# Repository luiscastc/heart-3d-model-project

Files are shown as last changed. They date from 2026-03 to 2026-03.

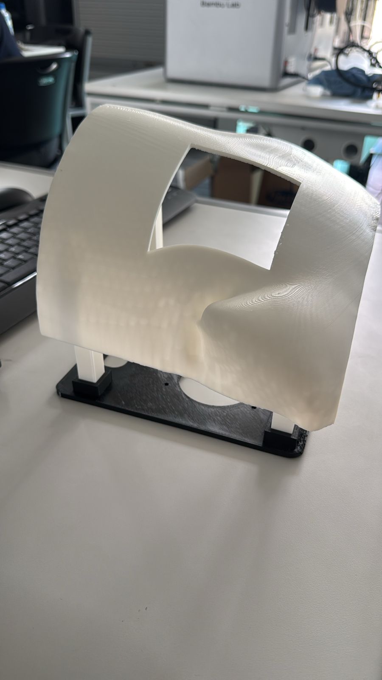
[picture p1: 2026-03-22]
images/printed-thoracic-cover.jpg

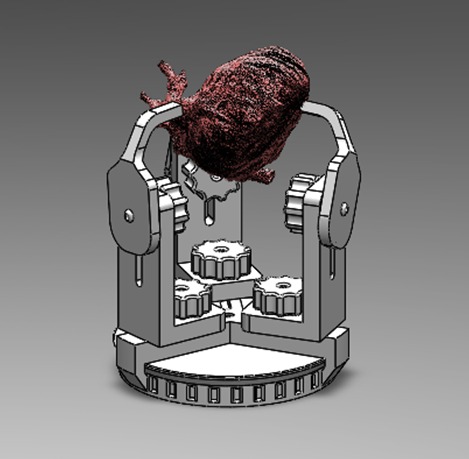
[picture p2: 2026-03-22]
images/heart-fixture-assembly.jpg

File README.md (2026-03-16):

---

# Manufacturing Workflow

The general workflow used in this project includes the following stages:

1. Selection of anatomical cardiac models representing structural heart diseases.
2. Preparation of digital models for additive manufacturing.
3. Selection of suitable flexible polymeric materials.
4. Fabrication of the physical model using additive manufacturing technologies.
5. Post-processing and preparation of the final educational model.

The complete manufacturing guide is provided in the **manual** directory.

---

# Applications

The models developed within this project are intended for:

- Medical education
- Anatomical training
- Simulation of structural heart conditions
- Communication between healthcare professionals and students
- Training environments for medical device development

---

# Model Source

The anatomical heart models used in this project were obtained from the **3D Heart Project**, which provides segmented cardiac models for educational and research purposes.

3D Heart Project  
https://www.3dheartproject.com

The original models remain the property of their respective creators. This repository only documents the manufacturing methodology used to fabricate physical models for educational use.

---

# Intended Use

The models described in this repository are intended exclusively for:

- Educational purposes
- Training and simulation environments

These models are **not intended for patient-specific surgical planning or clinical decision-making**.

---

# Project Context

This work was developed as part of a graduate research project in the field of **medical device engineering**, focused on the development of accessible cardiac models that can support medical education and simulation.

The objective is to explore fabrication methodologies that enable the creation of realistic cardiac models using flexible polymeric materials and additive manufacturing.

---

# License

This repository is released under the **MIT License**.  
See the LICENSE file for additional information.

---

# Acknowledgments

The author acknowledges the contribution of the **3D Heart Project** for providing high-quality segmented cardiac models that enable research and educational initiatives in cardiovascular medicine.

---

# Contact

For questions related to the manufacturing process or the project, please open an issue in this repository.

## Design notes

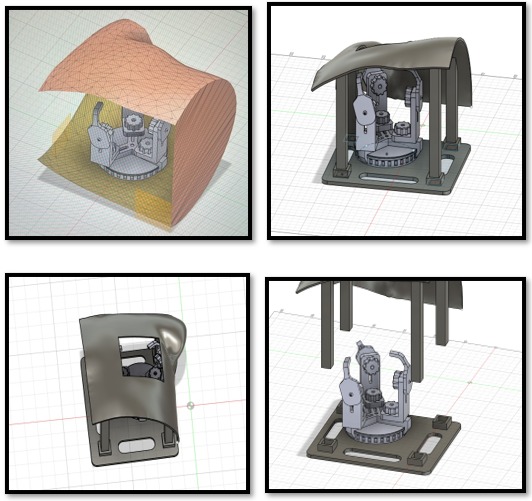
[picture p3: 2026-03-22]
images/support-concept-collage.jpg

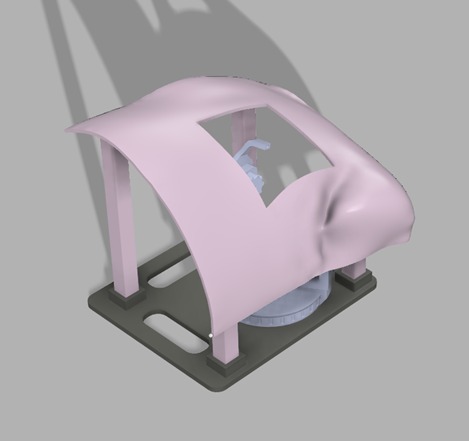
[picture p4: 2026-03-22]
images/cad-thoracic-cover.jpg

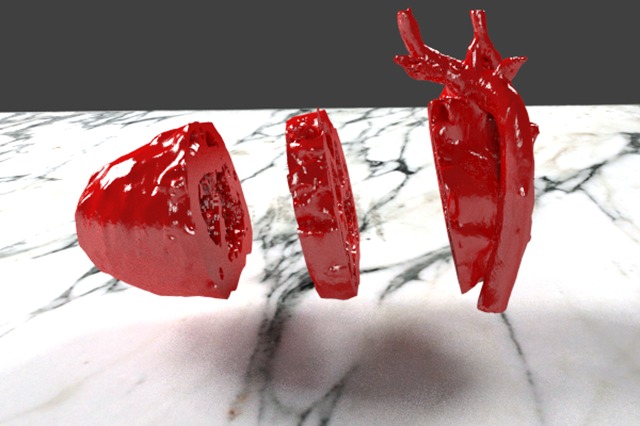
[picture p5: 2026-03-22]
images/heart-model-cross-sections.jpg

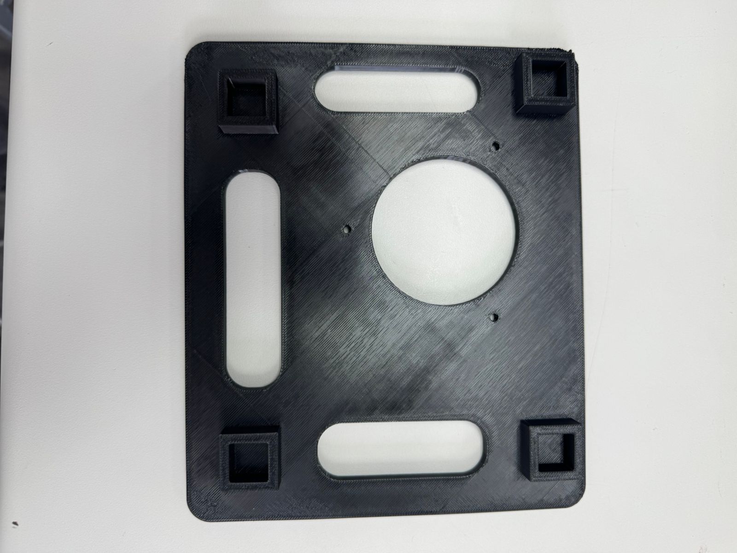
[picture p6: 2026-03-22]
images/base-platform.jpg

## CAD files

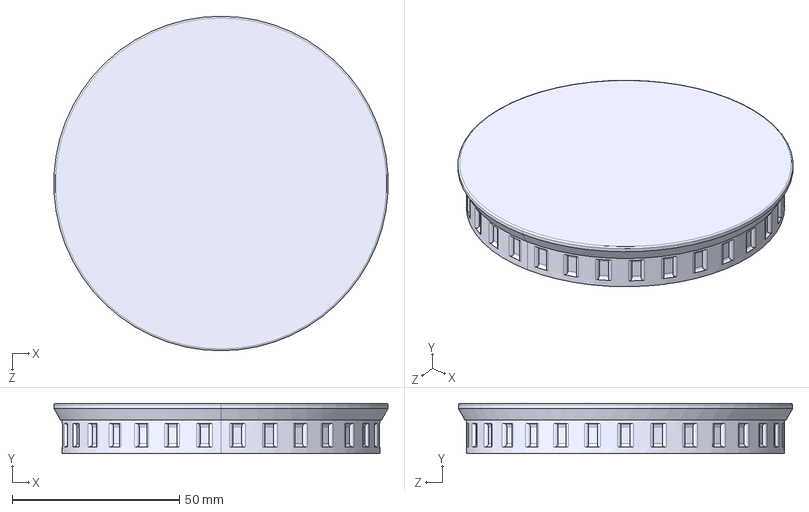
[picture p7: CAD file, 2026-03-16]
Fixture/Heart holder/Plato BaseVer2.STEP
99.9 x 15.0 x 100.0 mm

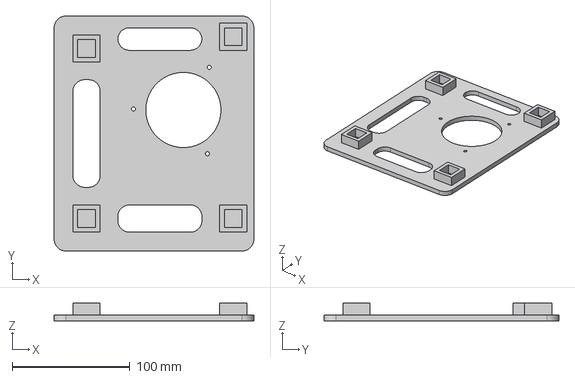
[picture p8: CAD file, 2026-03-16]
Fixture/Test bench/Base.step
170.0 x 200.0 x 15.0 mm

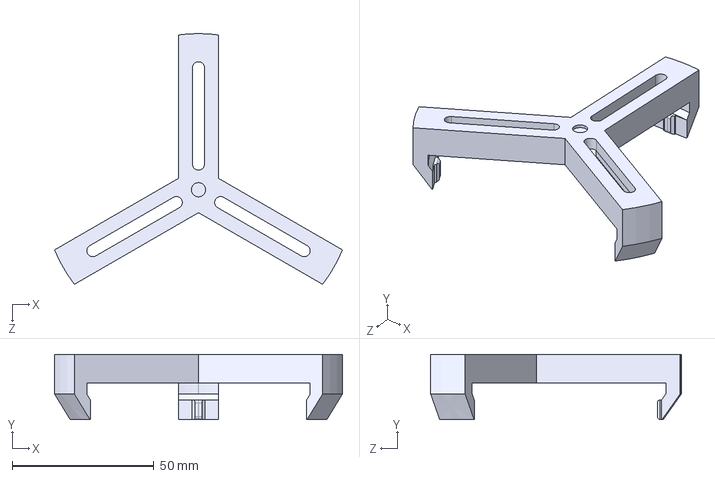
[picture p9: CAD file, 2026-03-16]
Fixture/Heart holder/GuiaAVer2.STEP
101.5 x 23.0 x 88.3 mm

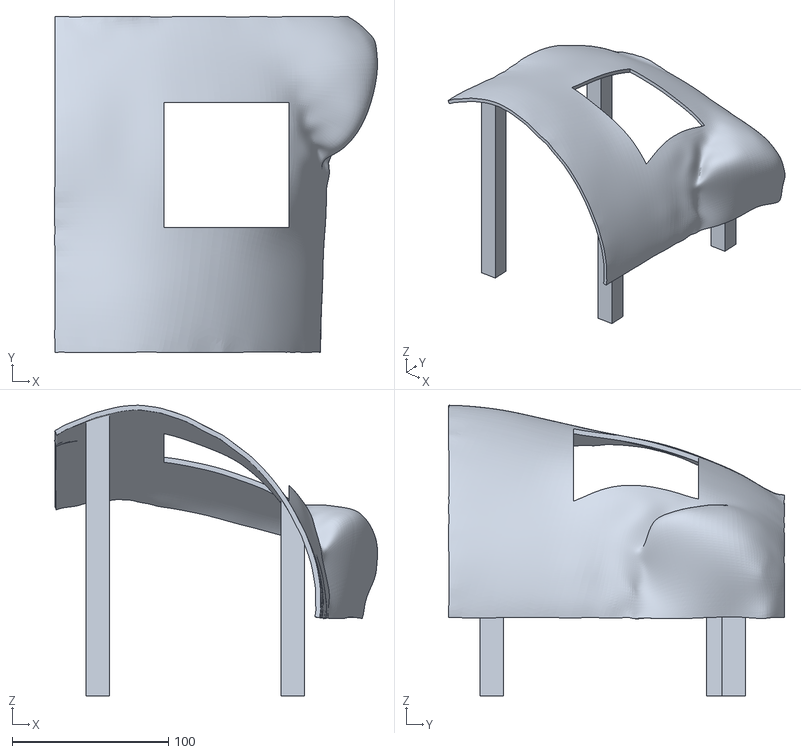
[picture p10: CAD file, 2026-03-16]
Fixture/Test bench/Chest.stl
206.9 x 215.4 x 186.1

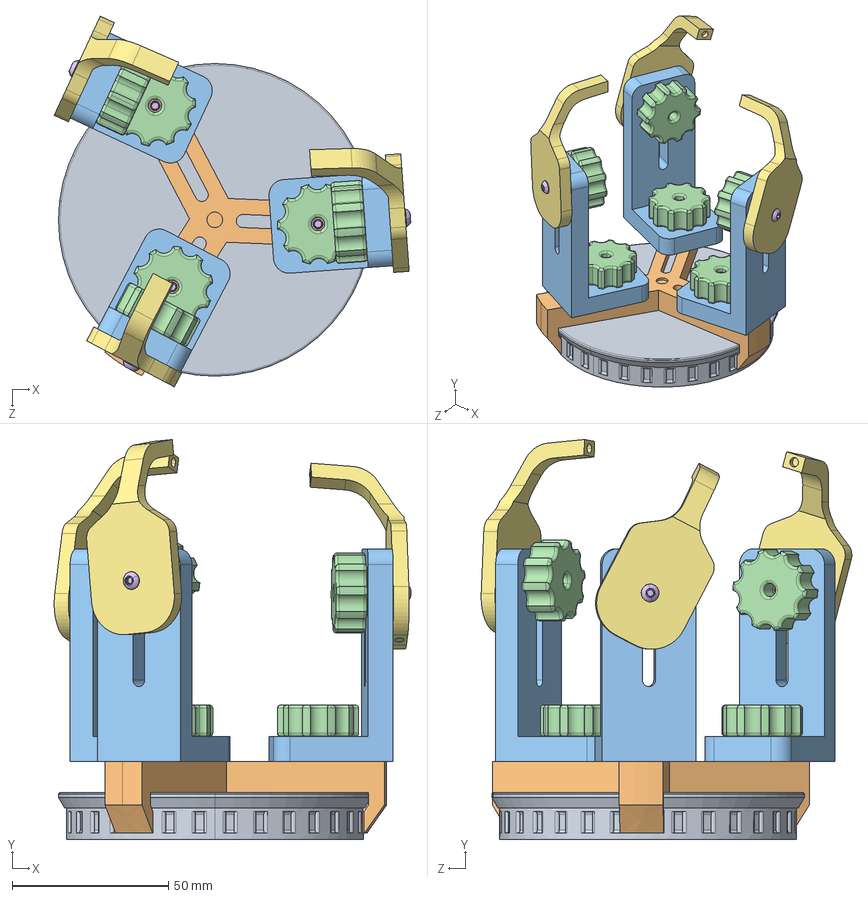
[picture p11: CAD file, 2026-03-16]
Fixture/Heart holder/Fixture Assem Ver2Ver2.STEP
114.1 x 128.0 x 118.6 mm
Plato BaseVer2
GuiaAVer2
Brazo1Ver2 x 3
ThumbwheelVer2 x 6
90592A085_Steel Hex NutVer2_90592A085 x 9
92095A184_Button Head Hex Drive ScrewVer2_92095A184 x 6
Brazo3Ver2_Garra x 3
Iman 3x2Ver2 x 3

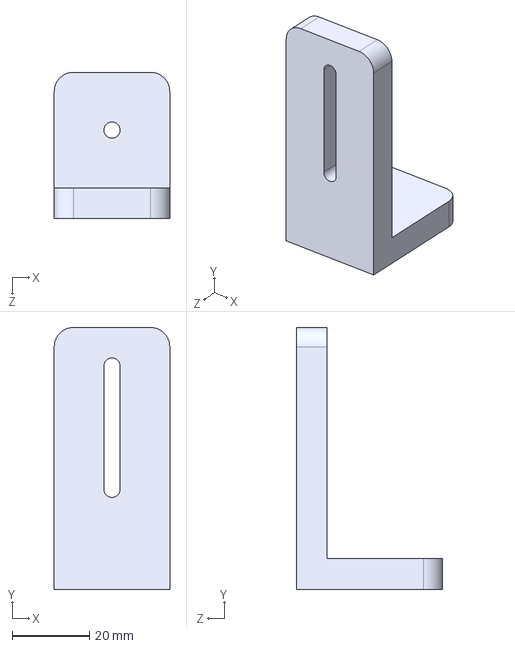
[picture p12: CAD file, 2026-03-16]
Fixture/Heart holder/Brazo1Ver2.STEP
30.0 x 68.0 x 38.0 mm

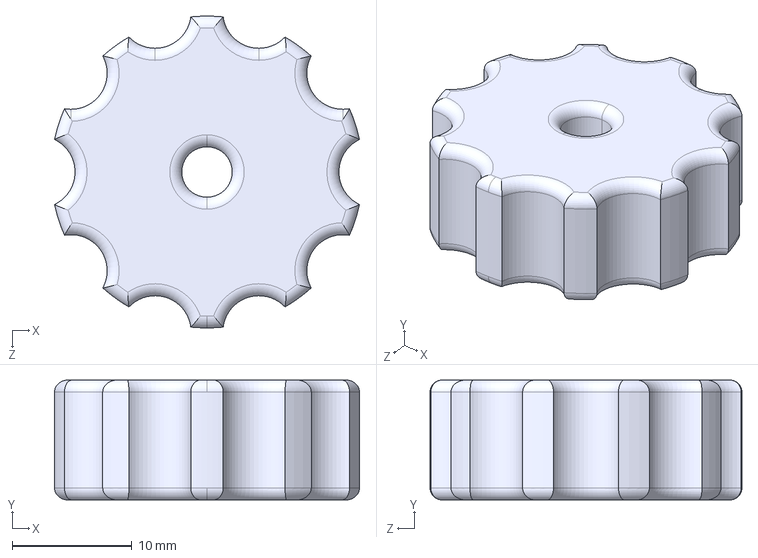
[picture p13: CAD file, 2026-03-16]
Fixture/Heart holder/ThumbwheelVer2.STEP
25.4 x 10.0 x 26.0 mm

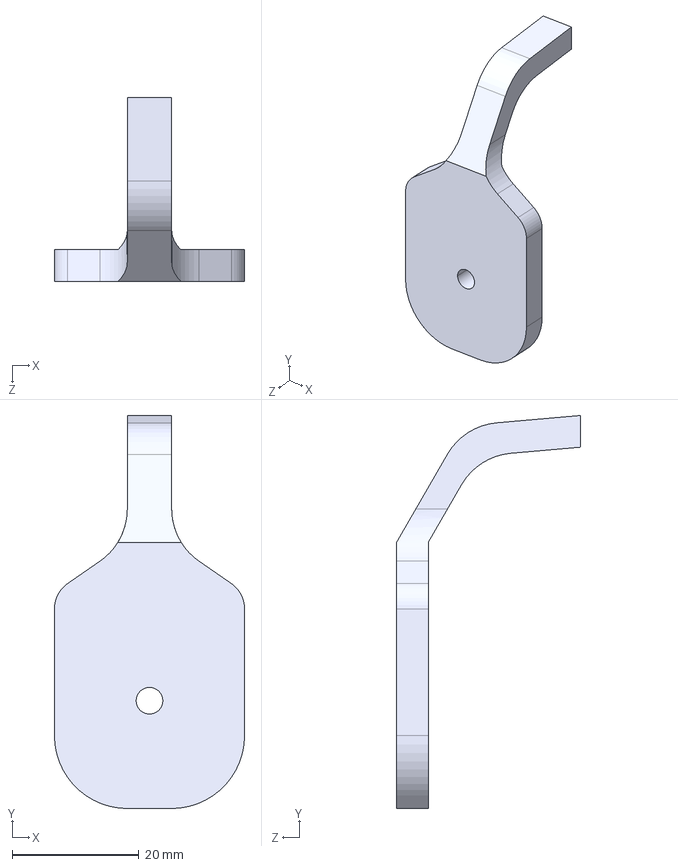
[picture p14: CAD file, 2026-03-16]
Fixture/Heart holder/Brazo3Ver2.STEP
30.0 x 62.0 x 29.0 mm

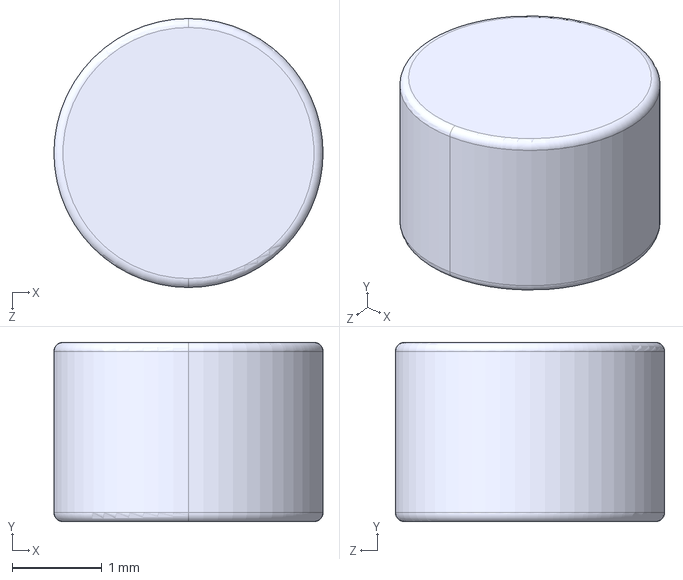
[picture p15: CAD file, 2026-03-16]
Fixture/Heart holder/Iman 3x2Ver2.STEP
3.00 x 2.00 x 3.00 mm

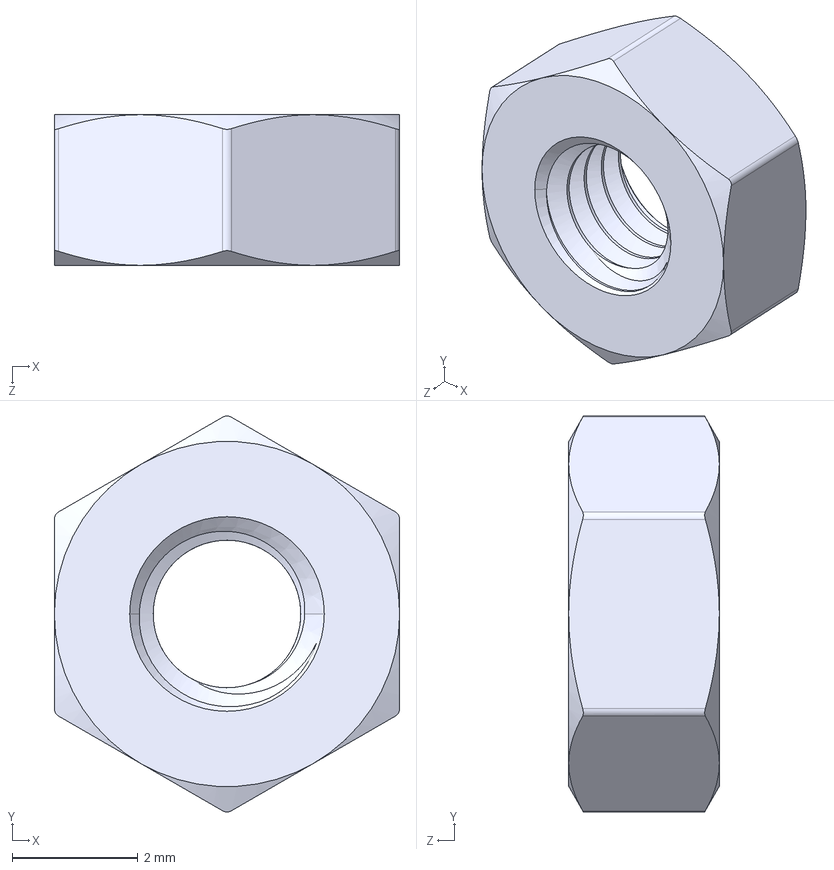
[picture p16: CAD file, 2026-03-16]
Fixture/Heart holder/90592A085_Steel Hex NutVer2.STEP
5.50 x 6.31 x 2.40 mm

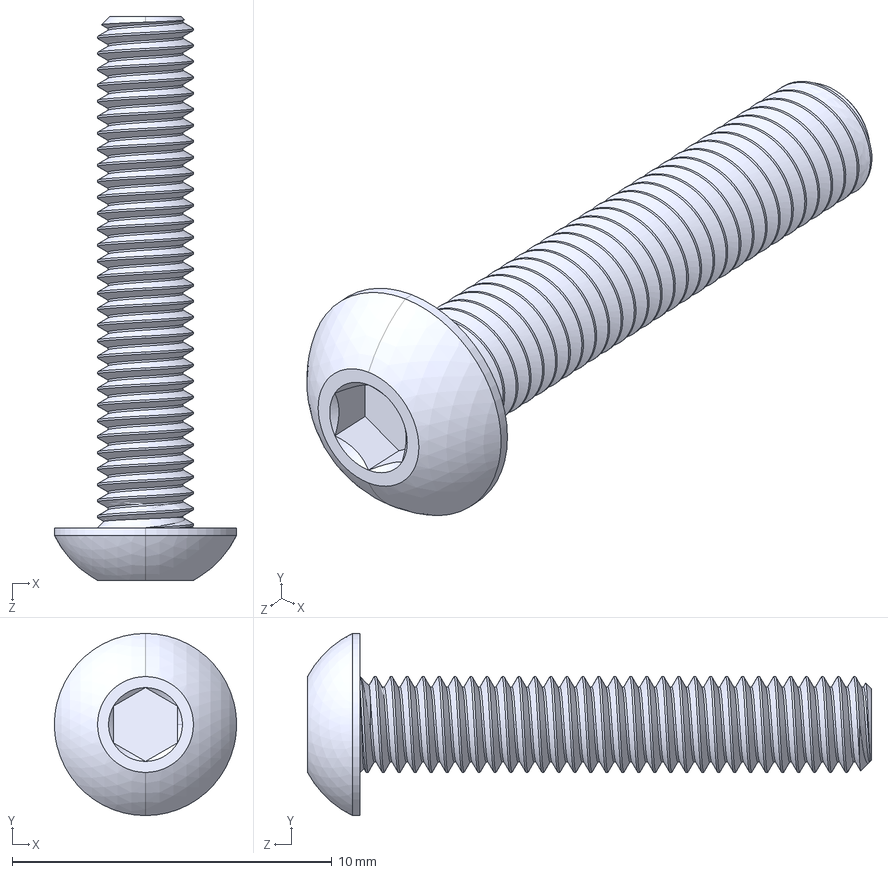
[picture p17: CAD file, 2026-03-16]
Fixture/Heart holder/92095A184_Button Head Hex Drive ScrewVer2.STEP
5.70 x 5.70 x 17.7 mm

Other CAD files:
Fixture/Heart holder/3D_Heart_Model_TOF_WholeVer2.STEP
Fixture/Test bench/base.stl

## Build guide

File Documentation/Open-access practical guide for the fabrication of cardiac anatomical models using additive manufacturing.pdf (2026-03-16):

Open-access practical guide for the fabrication of cardiac anatomical models using additive manufacturing

### 1. Introduction and Purpose of the Guide

This guide describes a reproducible workflow for the acquisition, preparation, manufacturing, post-processing, and validation of three-dimensionally printed anatomical cardiac biomodels intended primarily for educational and anatomical simulation applications.

The development of cardiac biomodels using additive manufacturing has made it possible to tangibly represent complex cardiac structures, facilitating the spatial understanding of structural heart diseases that are often difficult to interpret using only two-dimensional medical images. However, one of the main obstacles to their adoption in academic settings remains the lack of clear and reproducible guidelines documenting the entire manufacturing process.

In response to this need, this appendix proposes a reproducible, open-access guide that documents the workflow for manufacturing cardiac biomodels, including the following stages:

- Obtaining the digital model
- Preparing the model for manufacturing
- Preparing the file for printing
- Fabrication using additive manufacturing
- Post-processing of the biomodel
- Anatomical and functional evaluation

This guide is based on the experience gained during a final graduation project focused on the development of physical models of hearts with structural heart diseases using additive manufacturing and flexible polymeric materials.

Although the research used a pediatric heart with Tetralogy of Fallot as a case study, the procedure described can be applied to any cardiac model available in a digital format suitable for 3D printing.

The guide specifies Formlabs Silicone 40A elastomer as the manufacturing material, selected during the project’s experimental phase for its mechanical properties suitable for simulating soft tissues. It is important to note that, at the time of this guide’s preparation, this material is commercially available only in black, which may limit the visual differentiation of certain anatomical structures. This characteristic is common in elastomeric materials recently introduced to the market and could be modified in future versions of the material through pigmented variants. Alternatives such as the use of coatings or surface pigmentation of the model are not within the scope of this work.

### 2. Scope of the Guide

This guide is intended for the fabrication of flexible cardiac biomodels for non-clinical purposes using additive manufacturing, digital anatomical models, and Formlabs’ Silicone 40A elastomeric material.

Its intended applications include:

- Anatomical education
- Demonstration of congenital heart conditions
- Basic hands-on training in handling cardiac structures
- Simulation of manipulation and suturing on simulated tissues
- Visual support in academic, teaching, or technical communication contexts

The guide can be applied to anatomical models representing structural heart diseases, provided that the digital file has sufficient geometric quality for three-dimensional preparation and printing.

The following are not within the scope of this document:

- The use of the biomodel for personalized surgical planning for specific patients
- Direct clinical decision-making based on the physical model

### 3. Rationale and justification for the proposed workflow

The proposed workflow is based on the results obtained during the project’s experimental phase, in which various additive manufacturing technologies and flexible materials were evaluated for the fabrication of anatomical cardiac models.

Technologies accessible in academic settings were analyzed, such as FDM with flexible materials (e.g., TPU) and elastomeric photopolymerizable resin systems. Although these alternatives offer advantages in terms of cost and availability, they presented limitations in surface fidelity, precision in complex geometries, and behavior during handling.

PolyJet technology, recognized for its high resolution and surface quality, was also evaluated. However, its use proved less practical due to the limited availability of equipment, high operating costs, and reliance on specialized suppliers. Furthermore, in the proof-of-concept tests conducted during the project, the materials evaluated using this technology showed limited performance in cutting and suturing tests, which affects their usefulness in handling and training activities.

Based on this comparative evaluation, Formlabs’ Silicone 40A material was selected, as it demonstrated an appropriate balance between geometric fidelity, elastomeric behavior, and resistance to repeated manipulation. Based on these results, the guide proposes a simplified workflow that allows for the reproduction of the biomodel’s fabrication without the need to repeat the entire material and technology comparison phase.

Consequently, the workflow is structured into the following main stages:

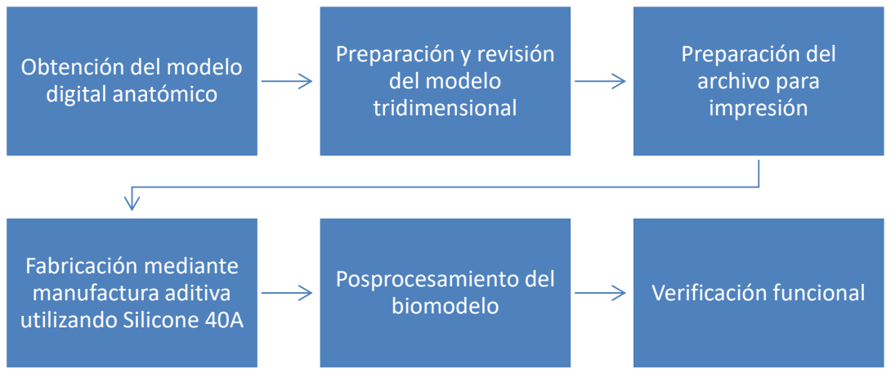
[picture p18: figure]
Obtención del modelo digital anatómico; Preparación y revisión del modelo tridimensional; Preparación del archivo para impresión; Fabricación mediante manufactura aditiva utilizando Silicone 40A; Posprocesamiento del; biomodelo; Verificación funcional

### 4. Components of the simulation system

The physical system described in this guide consists of three main elements that allow the cardiac biomodel to be integrated into a stable manipulation environment:

- Flexible cardiac biomodel
- Anatomical support base
- Structural thoracic cover (optional depending on application)

Each component fulfills a specific function within the simulation system.

The flexible cardiac biomodel is the main anatomical component and is manufactured using additive manufacturing with Silicone 40A.

The anatomical support base allows the heart to be positioned stably during manipulation, demonstration, or training activities.

The structural thoracic cover can be used to partially represent the thoracic cavity, providing additional anatomical context during educational demonstrations.

### 5. Obtaining digital anatomical models

### 5.1. Source of the models

The digital models used in this guide come from repositories specializing in cardiac anatomy that are used for research and medical education.

This study uses models from the 3D Heart Project repository, which are already segmented and prepared for educational and research use.

The use of pre-segmented models allows the work to focus on the manufacturing and validation process of the physical biomodel, significantly reducing the time associated with medical image processing.

### 5.2. Model Format

Digital models must be in one of the following formats compatible with additive manufacturing:

- STL
- OBJ
- PLY

The STL format is the most commonly used format in additive manufacturing and will be the primary format used in this guide.

### 6. Preparing the Model for Manufacturing

Preparing the digital model is a critical step to ensure that the anatomical geometry can be correctly fabricated using additive manufacturing and that the final biomodel exhibits sufficient mechanical stability during handling. This section describes the steps used to prepare the cardiac model using Meshmixer, a widely used software for editing and repairing three-dimensional meshes.

The objective of this stage is to ensure that the model meets the following requirements prior to fabrication:

- Geometric integrity of the mesh (watertight model)

- Absence of topological errors
- Structural stability of the printed model
- Preservation of relevant anatomical structures

The steps described below correspond to the workflow used in the preparation of cardiac biomodels.

### 6.1. Mesh inspection and repair (Watertight)

Before preparing the model for printing, it is necessary to verify that the geometry is completely closed (watertight). An open model can cause failures during the printing process or produce incorrect geometric results.

Procedure in Meshmixer

1. Import the model file in STL format into Meshmixer.
2. Go to the menu:

Analysis → Inspector

3. The system will automatically perform a mesh analysis and highlight potential errors using color indicators.

The most common errors include:

- Holes in the surface
- Open edges
- Geometry intersections
- Inverted faces
4. Select Auto Repair All to automatically close small openings in the mesh.

In the case of larger openings or complex defects, manual corrections may be necessary using surface editing tools.

Once the repair is complete, the model should be a fully closed surface, a necessary condition for correct volume generation during printing.

### 6.2. Selective Surface Smoothing

Models derived from medical segmentation processes or digital repositories may exhibit surface irregularities or geometric artifacts. Surface smoothing allows for improved model quality without altering its overall anatomical shape.

However, it is essential to avoid modifications to critical anatomical structures, especially in regions such as the interventricular septum, where small geometric alterations could affect the anatomical representation of the pathology.

Procedure in Meshmixer

1. Access the menu:

Select

2. Use the selection tools to identify surface areas with irregularities.
3. Go to:

Sculpt → Smooth

4. Apply smoothing locally and progressively, using moderate intensity values.

During this process, it is recommended that you:

- Apply smoothing only to external surfaces
- Avoid areas of anatomical interest
- Do not modify the geometry of the interventricular septum

The goal is to improve surface continuity without compromising the anatomical accuracy of the model.

### 6.3. Model scaling

Depending on the source of the digital model, it may be necessary to verify or adjust the scale to ensure that the biomodel accurately represents the anatomical dimensions.

Procedure in Meshmixer

1. Go to:

Edit → Transform

2. Review the model’s current dimensions.
3. If necessary, apply a uniform scale factor to adjust the model’s size.

It is recommended to maintain uniform scaling along all three axes (X, Y, Z) to avoid geometric distortions.

In educational applications, the model can be kept at actual scale or adapted to dimensions that facilitate its manipulation during demonstrations.

### 6.4. Generating minimum wall thickness

Models derived from medical segmentation may contain extremely thin surfaces that are structurally unstable during printing with elastomeric materials.

To ensure the stability of the biomodel manufactured with Silicone 40A, a minimum wall thickness of 2 mm is established.

This thickness allows for:

- Maintain the structural integrity of the model
- Prevent deformation during handling
- Improve resistance to shear or suture forces

Procedure in Meshmixer

1. Access the menu:

Edit → Make Solid

2. Set the main parameters:

Solid Type: Accurate

Solid Accuracy: high

Mesh Density: medium or high

Minimum Thickness: 2 mm

3. Apply the operation to generate a solid geometry with uniform thickness.

It is recommended to review the geometry again using:

Analysis → Inspector

to confirm that the resulting model remains completely closed and free of topological errors.

### 6.5. Exporting the prepared model

Once the repair, smoothing, scaling, and thickness generation steps are complete, the model can be exported again in STL format for preparation in the corresponding printing software.

This file constitutes the final version of the digital model, ready for the print preparation and additive manufacturing stage.

### 7. Manufacturing of the flexible cardiac biomodel

The flexible cardiac biomodel is the main anatomical component of the simulation system. It is manufactured using additive manufacturing with Formlabs’ Silicone 40A , an elastomer specifically designed for applications requiring flexibility, tear resistance, and geometric stability after curing.

The model is manufactured using resin printers from the Formlabs Form 4 platform, with PreForm software used to prepare the print file. At this stage, it is essential to properly configure the model’s orientation, support generation, and print parameters to ensure the geometric quality of the biomodel and avoid defects associated with the behavior of elastomeric materials during the manufacturing process.

### 7.1. File Preparation in PreForm

The model, previously prepared in STL format, must be imported into the PreForm software, which is used to configure the printing process on Formlabs systems.

General procedure

1. Open PreForm.
2. Import the STL file using the option:

File → Open

3. Select the printing material:

Material → Silicone 40A

When you select the material, the software automatically adjusts the print profiles compatible with this elastomer, including the exposure strategy and layer settings used by the printer.

Next, proceed with model orientation and support generation, aspects that have a direct impact on the final quality of the part.

### 7.2. Model Orientation

Model orientation within the print volume is a critical factor when working with elastomeric materials, as improper orientation can lead to defects such as:

- Trapped liquid resin
- Internal bubble formation
- Deformations during curing
- Collapse of thin surfaces

To minimize these risks, it is recommended to orient the model so that internal cavities facilitate resin drainage during printing, preventing areas where liquid material could become trapped. Additionally, it is advisable to avoid having large surfaces that are completely parallel to the print bed, as this can generate additional stresses during the process. Finally, care should be taken to ensure that the most delicate anatomical regions of the model have adequate support to guarantee their stability and preserve the accuracy of the geometry during manufacturing.

In the case of cardiac models, it is usually advisable to apply a moderate tilt to the model (approximately between 20° and 40°) relative to the printing platform. This tilt facilitates:

- Resin drainage from internal cavities
- A more uniform distribution of release forces
- A reduction in the risk of bubble formation or local collapses

The final orientation should be visually evaluated in PreForm to ensure that complex anatomical structures (e.g., vessels or cavities) are not oriented in a way that could trap liquid resin during the process.

### 7.3. Support Generation for Elastomeric Materials

Elastomeric materials behave differently from rigid resins during printing. Due to their flexibility, parts can deform more easily during the release phases of each layer.

For this reason, it is recommended to use a higher support density than is typically used for rigid materials.

Recommended settings

In PreForm, supports can be generated using the option:

Supports → Auto Generate Selected

It is recommended to manually review the generated supports afterward.

General recommendations include:

- Use medium to high support density
- Reinforce the lower areas of the model
- Add additional supports on large surfaces
- Ensure support for thin or overhanging geometries

It is also important to avoid, as much as possible, placing supports in critical anatomical areas that must remain visually clean to facilitate subsequent observation or manipulation. Proper support placement helps reduce warping during the printing process, maintain model stability throughout manufacturing, and improve the geometric accuracy of the final biomodel.

### 7.4. Print settings in Form 4 for Silicone 40A

The print parameters used for Silicone 40A on the Form 4 printer are preconfigured within the material profile in PreForm. However, it is important to understand the key parameters that influence the manufacturing process.

The most relevant parameters include:

Parameter | Recommended settings
Printing technology | LFD (Low Force Display)
Layer height | Automatically defined by the material profile
Material | Silicone 40A
Exposure strategy | Automatically controlled by PreForm
Supports | Automatically generated and manually adjusted
Post-curing | Described in Section 9 of this guide

The LFD (Low Force Display) technology used by the Form 4 reduces detachment forces during printing, which is particularly important when manufacturing flexible parts or complex geometries.

Once these parameters have been configured and the model orientation verified, the file can be sent to the printer to start the manufacturing process for the flexible cardiac biomodel.

It is important that the model has been previously prepared with a minimum wall thickness of 2 mm, as described in Section 6.4. Thinner walls may cause deformation during printing or compromise the integrity of the biomodel during handling.

Correct configuration of these variables allows for the production of biomodels with high anatomical fidelity, structural stability, and mechanical behavior suitable for simulation and manipulation activities.

### 8. Fabrication of the Anatomical Support Base and Structural

Components

The structural components of the system have been designed to provide mechanical stability to the flexible biomodel and contextualize the simulation practice. These files are available in the attached repository in STL format and are optimized for fabrication using Fused Deposition Modeling (FDM).

### 8.1. Recommended material

PLA is the standard material for manufacturing the support base and thoracic cover.

PLA offers high structural rigidity, low thermal shrinkage (warping), and ease of printing on conventional equipment. Since these parts do not require contact with biological fluids or aggressive sterilization processes, PLA ensures the system’s stability at minimal cost.

### 8.2. Print Settings (Slicing)

To ensure that the fastening mechanisms (specifically the "claw" system and pivot points) maintain their integrity during user handling, the following print parameters are recommended:

Parameter | Recommended Setting
Layer height | 0.2 mm (Balance between resolution and
time)
Wall thickness (Perimeters) | Minimum 3 layers (Essential for joint
strength)
Infill | 15%–20%
Infill pattern | Helical or Grid (Provides multidirectional
strength)
Top/bottom layers | 4 layers
Nozzle temperature | As | per | manufacturer’s | specifications
(Typically 200°C - 215°C)

### 8.3. Clamping design considerations

The anatomical support base features a claw-type clamping mechanism specifically designed to interact with low-hardness elastomers (such as 40A silicone).

Mechanical adjustment: After printing, verify that the mechanism’s clamps move freely. In case of excessive friction due to printer tolerances, light sanding of the shaft contact areas is recommended.

Interface with the biomodel: The design allows the heart to be “embraced” by the claw, distributing contact pressure to prevent tears in the flexible material during suturing or manipulation.

### 8.4. Assembly with the pediatric thoracic cover

Once the structural components have been manufactured using FDM printing, the simulation system is assembled, integrating the anatomical support base, the flexible cardiac biomodel, and the pediatric thoracic cover.

The system’s design allows for modular assembly, so that the user can use the heart with just the support base or additionally integrate the thoracic cage when a more complete anatomical context is required.

The recommended assembly procedure is as follows:

### 1. Installing the biomodel on the support base

The flexible cardiac biomodel should be placed between the claws of the clamping mechanism. The clamps of the claw-type system are designed to exert moderate pressure to stabilize the model without causing permanent deformation of the elastomer.

### 2. Verification of stability

Once the biomodel is positioned, verify that the model remains stable during manipulation. The system should allow for moderate manual movements without the heart shifting or rotating within the clamping mechanism.

### 3. Assembly of the pediatric thoracic cover

The thoracic cover can be installed by aligning the designed attachment points on the structural base. These attachment points allow the cover to be positioned consistently, maintaining the system’s correct anatomical orientation.

### 4. Final adjustment of the system

After assembly, it is recommended to verify that:

- The cover does not interfere with access to the biomodel during practice
- The biomodel remains visible from the main observation angles

- The structural components do not exert excessive compression on the elastomeric material

This integration system allows for the recreation of a simplified anatomical environment of the pediatric thorax, facilitating spatial understanding of cardiac structures and enhancing the simulation experience during educational or demonstration activities.

The system’s modular design also allows components to be easily disassembled for maintenance, replacement of the biomodel, or transport of the system, while maintaining the overall functionality of the assembly.

### 9. Post-processing of the biomodel

Post-processing is a critical step in the fabrication of biomodels printed with Silicone 40A, as it largely determines the final mechanical properties of the material, the surface quality of the model, and the removal of uncured material residue.

Due to the elastomeric nature of the material, the cleaning procedure differs from that of other photopolymers used in additive manufacturing. This section describes the recommendations based on Formlabs’ technical guidelines, adapted to the workflow of this guide.

### 9.1. Washing the Printed Biomodel

According to the manufacturer’s recommendations, the standard cleaning procedure for Silicone 40A consists of washing using a solvent mixture within a Form Wash system.

The standard procedure recommended by Formlabs uses:

20% n-butyl acetate + 80% isopropyl alcohol (IPA) for 20 minutes.

However, due to the characteristic odor of n-butyl acetate, the manufacturer also describes an alternative procedure using only IPA and ultrasonic cleaning, which was considered in this workflow.

Alternative procedure with IPA and ultrasonic bath

1. Remove the model from the print bed.
2. Place the parts in a container with enough IPA to completely cover the model.
3. Place the container inside an ultrasonic bath filled with water.

Formlabs recommends using ultrasonic cleaners in the range of:

35–45 kHz

4. Sonicate the parts for 2 to 3 minutes.

During washing, it is normal to observe that the IPA becomes cloudy or that silicone residues appear in suspension, since silicone is not soluble in IPA.

5. Repeat the process using clean IPA in a second container to ensure complete removal of residues.

A properly cleaned part should not have any visible silicone residue on its surface.

6. After washing, allow the parts to air dry for at least 30 minutes before beginning the curing process.

### 9.2. Removal of Support Structures

Removing supports from elastomeric materials requires greater care than with rigid resins, as the material can deform or tear if excessive force is applied.

It is recommended to remove the supports after washing, when the material still retains some flexibility.

Recommended tools:

- Precision tweezers
- Modeling cutters
- Scalpel or fine blade

Handling recommendations:

- Remove the main supports first
- Avoid sudden pulling
- Cut the supports close to their point of contact

The flexibility of 40A silicone allows the part to be bent slightly to access supports located in internal areas.

### 9.3. Final curing of the biomodel

After washing and removing the supports, the model must undergo a thermal and UV curing process to achieve its final mechanical properties.

The manufacturer recommends using the Form Cure system.

Recommended settings by Formlabs

Parameter | Settings

Material | Silicone 40A
Temperature | 60 °C
Time | 45 minutes

Procedure:

1. Place the parts in a glass container or UV-transparent container.
2. Completely submerge the parts in water.
3. Place the container inside the Form Cure unit.
4. Run the 45-minute cycle at 60 °C.

Immersion in water during curing helps to:

- Improve heat transfer
- Promote uniform polymerization
- Reduce surface defects

The manufacturer states that additional curing does not adversely affect the material, especially in thick or bulky parts.

10.Integration and assembly of the simulation system

Once the manufacturing and post-processing stages of the various components are complete, the simulation system is integrated. This stage involves assembling the flexible cardiac biomodel made of Silicone 40A with the anatomical support base printed in PLA and, when required, incorporating the structural thoracic cover.

The objective of this phase is to ensure that the biomodel remains stable during handling, maintains its correct anatomical orientation, and allows for the recreation of a working environment that facilitates demonstration, training, or basic simulation activities.

The system has been designed with a modular approach, allowing each component to be easily disassembled for maintenance, transport, or replacement of the biomodel.

### 10.1. Assembling the biomodel onto the support base

The first step in assembly consists of securing the flexible cardiac biomodel within the claw-type clamping mechanism located on the anatomical support base.

This mechanism is designed to interact with low-hardness elastomeric materials, such as 40A silicone, allowing the model to be secured without compromising its structural integrity.

Assembly procedure:

1. Place the cardiac biomodel between the clamps of the claw-type clamping system.
2. Gradually adjust the opening of the clamps until the model is firmly held in place.
3. Verify that the pressure applied is sufficient to prevent the model from shifting, but without excessively compressing the elastomeric material.

Due to the flexible nature of Silicone 40A, excessive compression can cause deformations in the anatomical geometry and alterations in the shape of the internal cavities. For this reason, the clamping system should exert only the pressure necessary to stabilize the biomodel.

### 10.2. Anatomical orientation of the biomodel

Correct anatomical orientation of the model is essential for simulation activities to consistently replicate the typical perspective of the surgeon or student while manipulating the heart.

When installing the biomodel on the base, it is recommended to verify the following anatomical landmarks:

- The cardiac apex should be oriented toward the lower region of the system.
- The great vessels (aorta and pulmonary artery) should be oriented toward the upper region of the model.
- The anterior surface of the heart should face the user’s access area.

This orientation allows the model to reproduce an anatomical position approximating that of the heart within the thoracic cavity, facilitating the spatial interpretation of cardiac structures during demonstrations or educational exercises.

When using models with complex congenital heart defects, it may be advisable to slightly adjust the orientation to improve visibility of the regions of interest.

### 10.3. Installation of the Thoracic Cover

Once the biomodel is installed on the support base, the structural thoracic cover can be attached; this cover provides a simplified representation of the pediatric thoracic cavity and offers greater anatomical context during simulation.

To install it, align the cover’s attachment points with the structural base and press gently until it is securely fastened. Once installed, the cover should be firmly in place without interfering with access to the biomodel.

This component partially limits the user’s field of view, helping to create handling conditions that more closely resemble a real surgical environment.

### 10.4. Final System Verification and Adjustments

After completing the system assembly, it is recommended to perform a brief verification to ensure the proper functioning of the assembly.

The following aspects should be checked:

- The biomodel remains firmly secured within the clamping mechanism
- There is no excessive compression of the elastomeric material
- The model maintains the correct anatomical orientation
- The thoracic cover is properly attached
- There are no loose or unstable components
- The user can access the biomodel without structural interference

It is also recommended to perform a light manipulation test, simulating typical movements during educational or demonstration activities, to confirm that the system maintains its stability.

Once these aspects have been verified, the system is ready for use in simulation activities, anatomical teaching, or clinical demonstrations within educational or research contexts.

11.Final notes and recommendations

This guide describes a reproducible workflow for the fabrication and integration of anatomical cardiac biomodels using additive manufacturing. Proper handling and storage of the system components help preserve the quality of the biomodel and facilitate its use in educational or demonstration activities.

### 11.1. Storage of Biomodels

Due to the elastomeric nature of Silicone 40A, the material may exhibit slight surface stickiness, which facilitates the accumulation of dust or particles during storage. To preserve the biomodel prior to use, it is recommended to:

- Store the biomodels in closed containers or protective cases.
- Keep them away from dust or lint.
- Avoid prolonged exposure to direct sunlight, as UV radiation can accelerate the degradation of the material.

When planning educational activities that involve handling, cutting, or suturing, it is recommended to have several pre-made biomodels available, as these types of procedures permanently alter the model’s geometry.

### 11.2. Use of the biomodel

Biomodels can be used in different educational contexts depending on the type of activity. In anatomical demonstrations or educational exhibits, the model can be handled without altering its structural integrity. However, when the biomodel is used for cutting or suturing practices, the model should be considered single-use, as these procedures permanently alter the elastomeric material.

### 11.3. Final Consideration

The availability of clear technical guidelines for the fabrication of anatomical biomodels helps facilitate the incorporation of physical simulation tools into educational settings. Using the workflow described in this document, it is possible to transform digital models into physical representations that support three-dimensional understanding of cardiac anatomy and enrich teaching and demonstration activities in the field of medical education.

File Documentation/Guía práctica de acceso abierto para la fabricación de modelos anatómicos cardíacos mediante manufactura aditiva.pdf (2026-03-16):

Guía práctica de acceso abierto para la fabricación de modelos

anatómicos cardíacos mediante manufactura aditiva

### 1. Introducción y propósito de la guía

La presente guía describe un flujo de trabajo reproducible para la obtención, preparación,

manufactura, posprocesamiento y validación de biomodelos cardíacos anatómicos impresos

en tres dimensiones destinados principalmente a aplicaciones educativas y de simulación

anatómica.

El desarrollo de biomodelos cardíacos mediante manufactura aditiva ha permitido representar

de forma tangible estructuras cardíacas complejas, facilitando la comprensión espacial de

cardiopatías estructurales que frecuentemente resultan difíciles de interpretar únicamente

mediante imágenes médicas bidimensionales. Sin embargo, uno de los principales obstáculos

para su adopción en contextos académicos sigue siendo la ausencia de guías claras y

reproducibles que documenten el proceso completo de fabricación.

En respuesta a esta necesidad, el presente anexo propone una guía reproducible y de acceso

abierto que documenta el flujo de trabajo para la fabricación de biomodelos cardíacos,

incluyendo las etapas de:

- Obtención del modelo digital
- Preparación del modelo para manufactura
- Preparación del archivo para impresión
- Fabricación mediante manufactura aditiva
- Posprocesamiento del biomodelo
- Evaluación anatómica y funcional

Esta guía se deriva de la experiencia obtenida durante el trabajo final de graduación orientado

al desarrollo de modelos físicos de corazones con enfermedades estructurales cardíacas

mediante manufactura aditiva y materiales poliméricos flexibles.

Aunque en la investigación se utilizó un corazón pediátrico con Tetralogía de Fallot como

caso de estudio, el procedimiento descrito puede aplicarse a cualquier modelo cardíaco

disponible en formato digital adecuado para impresión tridimensional.

La guía establece como material de fabricación el elastómero Silicone 40A de Formlabs,

seleccionado durante la fase experimental del proyecto por sus propiedades mecánicas

adecuadas para la simulación de tejidos blandos. Es importante considerar que, al momento

de elaboración de esta guía, este material se encuentra disponible comercialmente

únicamente en color negro, lo cual puede limitar la diferenciación visual de algunas

estructuras anatómicas. Esta característica es común en materiales elastoméricos

recientemente introducidos al mercado y podría modificarse en futuras versiones del material

mediante variantes pigmentadas. Alternativas como el uso de recubrimientos o pigmentación

superficial del modelo no forman parte del alcance del presente trabajo.

### 2. Alcance de la guía

Esta guía está orientado a la fabricación de biomodelos cardíacos flexibles con fines no

clínicos mediante manufactura aditiva, utilizando modelos anatómicos digitales y el material

elastomérico Silicone 40A de Formlabs.

Su aplicación prevista incluye:

- Educación anatómica
- Demostración de patologías cardíacas congénitas
- Entrenamiento práctico básico en manipulación de estructuras cardíacas
- Simulación de manipulación y sutura en tejidos simulados
- Apoyo visual en contextos académicos, docentes o de comunicación técnica

La guía puede aplicarse a modelos anatómicos representativos de cardiopatías estructurales,

siempre que el archivo digital cuente con una calidad geométrica suficiente para su

preparación e impresión tridimensional.

No forma parte del alcance de este documento:

- El uso del biomodelo para planificación quirúrgica personalizada de pacientes

específicos

- La toma de decisiones clínicas directas basadas en el modelo físico

### 3. Fundamento y justificación del flujo de trabajo propuesto

El flujo de trabajo propuesto se basa en los resultados obtenidos durante la fase experimental

del proyecto, en la cual se evaluaron distintas tecnologías de manufactura aditiva y materiales

flexibles para la fabricación de modelos cardíacos anatómicos.

Se analizaron tecnologías accesibles en entornos académicos como FDM con materiales

flexibles (por ejemplo, TPU) y sistemas de resinas fotopolimerizables elastoméricas. Aunque

estas alternativas ofrecen ventajas de costo y disponibilidad, presentaron limitaciones en

fidelidad superficial, precisión en geometrías complejas y comportamiento durante la

manipulación.

También se evaluó la tecnología PolyJet, reconocida por su alta resolución y calidad

superficial. Sin embargo, su uso resultó menos conveniente debido a la limitada

disponibilidad de equipos, el alto costo operativo y la dependencia de proveedores

especializados. Además, en las pruebas de concepto realizadas durante el proyecto, los

materiales evaluados mediante esta tecnología mostraron un desempeño limitado en pruebas

de corte y sutura, lo cual afecta su utilidad en actividades de manipulación y entrenamiento.

A partir de esta evaluación comparativa se seleccionó el material Silicone 40A de Formlabs,

que mostró un equilibrio adecuado entre fidelidad geométrica, comportamiento elastomérico

y resistencia a la manipulación repetida. Con base en estos resultados, la guía propone un

flujo de trabajo simplificado que permite reproducir la fabricación del biomodelo sin

necesidad de repetir la fase completa de comparación de materiales y tecnologías.

En consecuencia, el flujo de trabajo se estructura en las siguientes etapas principales:

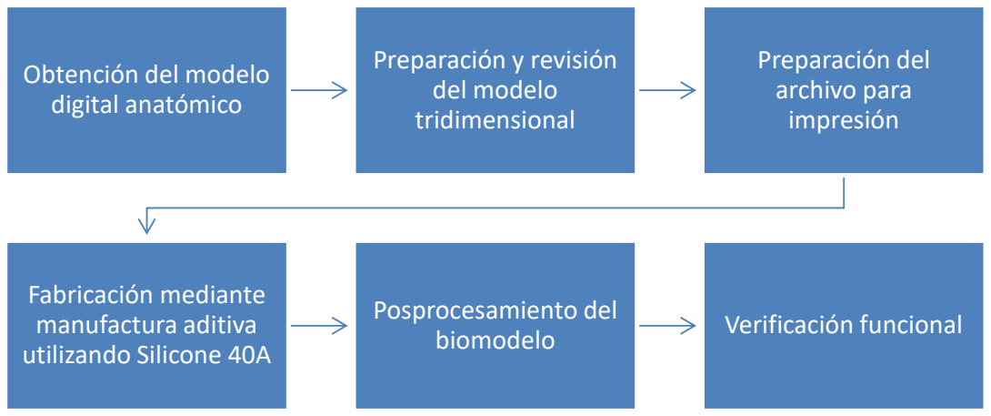
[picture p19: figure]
Obtención del modelo digital anatómico; Preparación y revisión del modelo tridimensional; Preparación del archivo para impresión; Fabricación mediante manufactura aditiva utilizando Silicone 40A; Posprocesamiento del; biomodelo; Verificación funcional

### 4. Componentes del sistema de simulación

El sistema físico descrito en esta guía está compuesto por tres elementos principales que

permiten integrar el biomodelo cardíaco dentro de un entorno de manipulación estable:

- Biomodelo cardíaco flexible
- Base de soporte anatómico
- Cubierta torácica estructural (opcional según aplicación)

Cada componente cumple una función específica dentro del sistema de simulación.

El biomodelo cardíaco flexible constituye el elemento anatómico principal y es fabricado

mediante manufactura aditiva utilizando Silicone 40A.

La base de soporte anatómico permite posicionar el corazón de forma estable durante las

actividades de manipulación, demostración o entrenamiento.

La cubierta torácica estructural puede utilizarse para representar parcialmente la cavidad

torácica, proporcionando un contexto anatómico adicional durante demostraciones

educativas.

### 5. Obtención de modelos digitales anatómicos

### 5.1. Fuente de los modelos

Los modelos digitales utilizados en esta guía provienen de repositorios especializados en

anatomía cardíaca utilizados para investigación y educación médica.

En este trabajo se emplean modelos provenientes del repositorio 3D Heart Project, los cuales

ya se encuentran segmentados y preparados para uso educativo y de investigación.

La utilización de modelos previamente segmentados permite enfocar el trabajo en el proceso

de manufactura y validación del biomodelo físico, reduciendo significativamente el tiempo

asociado al procesamiento de imágenes médicas.

### 5.2. Formato de los modelos

Los modelos digitales deben encontrarse en alguno de los siguientes formatos compatibles

con manufactura aditiva:

- STL
- OBJ
- PLY

El formato STL es el formato más comúnmente utilizado en manufactura aditiva y será el

formato principal utilizado en esta guía.

### 6. Preparación del modelo para manufactura

La preparación del modelo digital constituye una etapa crítica para garantizar que la

geometría anatómica pueda fabricarse correctamente mediante manufactura aditiva y que el

biomodelo final presente suficiente estabilidad mecánica durante la manipulación. En esta

sección se describen los pasos utilizados para preparar el modelo cardíaco utilizando

Meshmixer, un software ampliamente utilizado para edición y reparación de mallas

tridimensionales.

El objetivo de esta etapa es asegurar que el modelo cumpla con los siguientes requisitos antes

de su fabricación:

- Integridad geométrica de la malla (modelo watertight)
- Ausencia de errores topológicos
- Estabilidad estructural del modelo impreso
- Preservación de las estructuras anatómicas relevantes

Los pasos descritos a continuación corresponden al flujo de trabajo utilizado en la

preparación de los biomodelos cardíacos.

### 6.1. Inspección y reparación de la malla (Watertight)

Antes de preparar el modelo para impresión es necesario verificar que la geometría esté

completamente cerrada (watertight). Un modelo no cerrado puede generar fallos durante el

proceso de impresión o producir resultados geométricos incorrectos.

Procedimiento en Meshmixer

1. Importar el archivo del modelo en formato STL en Meshmixer.
2. Acceder al menú:

Analysis → Inspector

3. El sistema realizará automáticamente un análisis de la malla y marcará posibles

errores mediante indicadores de color.

Los errores más comunes incluyen:

- Agujeros en la superficie
- Bordes abiertos
- Intersecciones de geometría
- Caras invertidas
4. Seleccionar Auto Repair All para cerrar automáticamente pequeñas aperturas en la

malla.

En caso de aperturas mayores o defectos complejos, puede ser necesario realizar correcciones

manuales utilizando herramientas de edición de superficie.

Una vez completada la reparación, el modelo debe quedar como una superficie

completamente cerrada, condición necesaria para la generación correcta del volumen durante

la impresión.

### 6.2. Suavizado selectivo de la superficie

Los modelos derivados de procesos de segmentación médica o repositorios digitales pueden

presentar irregularidades superficiales o artefactos geométricos. El suavizado de la superficie

permite mejorar la calidad del modelo sin alterar su forma anatómica general.

Sin embargo, es fundamental evitar modificaciones en estructuras anatómicas críticas,

especialmente en regiones como el septum interventricular, donde pequeñas alteraciones

geométricas podrían afectar la representación anatómica de la patología.

Procedimiento en Meshmixer

1. Acceder al menú:

Select

2. Utilizar las herramientas de selección para identificar áreas de superficie que

presenten irregularidades.

3. Acceder a:

Sculpt → Smooth

4. Aplicar suavizado de forma local y progresiva, utilizando valores moderados de

intensidad.

Durante este proceso se recomienda:

- Aplicar suavizado únicamente en superficies externas
- Evitar zonas de interés anatómico
- No modificar la geometría del septum interventricular

El objetivo es mejorar la continuidad de la superficie sin comprometer la fidelidad anatómica

del modelo.

### 6.3. Escalamiento del modelo

Dependiendo del origen del modelo digital, puede ser necesario verificar o ajustar la escala

para garantizar que el biomodelo represente adecuadamente las dimensiones anatómicas.

Procedimiento en Meshmixer

1. Acceder a:

Edit → Transform

2. Revisar las dimensiones actuales del modelo.
3. Si es necesario, aplicar un factor de escala uniforme para ajustar el tamaño del

modelo.

Se recomienda mantener escalado uniforme en los tres ejes (X, Y, Z) para evitar distorsiones

geométricas.

En aplicaciones educativas, el modelo puede mantenerse en escala real o adaptarse a

dimensiones que faciliten su manipulación durante demostraciones.

### 6.4. Generación de espesor mínimo de paredes

Los modelos derivados de segmentación médica pueden contener superficies

extremadamente delgadas que resultan estructuralmente inestables durante la impresión con

materiales elastoméricos.

Para garantizar la estabilidad del biomodelo fabricado con Silicone 40A, se establece un

espesor mínimo de pared de 2 mm.

Este espesor permite:

- Mantener la integridad estructural del modelo
- Evitar deformaciones durante la manipulación

- Mejorar la resistencia a esfuerzos de corte o sutura

Procedimiento en Meshmixer

1. Acceder al menú:

Edit → Make Solid

2. Configurar los parámetros principales:

Solid Type: Accurate

Solid Accuracy: alta

Mesh Density: media o alta

Minimum Thickness: 2 mm

3. Aplicar la operación para generar una geometría sólida con espesor uniforme.

Posteriormente se recomienda revisar nuevamente la geometría utilizando:

Analysis → Inspector

para confirmar que el modelo resultante se mantiene completamente cerrado y libre de errores

topológicos.

### 6.5. Exportación del modelo preparado

Una vez finalizados los pasos de reparación, suavizado, escalamiento y generación de

espesor, el modelo puede exportarse nuevamente en formato STL para su preparación en el

software de impresión correspondiente.

Este archivo constituye la versión final del modelo digital lista para la etapa de preparación

de impresión y manufactura aditiva.

### 7. Fabricación del biomodelo cardíaco flexible

El biomodelo cardíaco flexible constituye el componente anatómico principal del sistema de

simulación. Su fabricación se realiza mediante manufactura aditiva utilizando Silicone 40A de Formlabs, un elastómero diseñado específicamente para aplicaciones que requieren

flexibilidad, resistencia al desgarro y estabilidad geométrica después del curado.

La fabricación del modelo se realiza utilizando impresoras de resina de la plataforma

Formlabs Form 4, empleando el software PreForm para la preparación del archivo de

impresión. En esta etapa es fundamental configurar adecuadamente la orientación del

modelo, la generación de soportes y los parámetros de impresión, con el fin de garantizar la

calidad geométrica del biomodelo y evitar defectos asociados al comportamiento de

materiales elastoméricos durante el proceso de fabricación.

### 7.1. Preparación del archivo en PreForm

El modelo previamente preparado en formato STL debe importarse en el software PreForm,

utilizado para la configuración del proceso de impresión en sistemas Formlabs.

Procedimiento general

1. Abrir PreForm.
2. Importar el archivo STL mediante la opción:

File → Open

3. Seleccionar el material de impresión:

Material → Silicone 40A

Al seleccionar el material, el software ajusta automáticamente los perfiles de impresión

compatibles con este elastómero, incluyendo la estrategia de exposición y las configuraciones

de capa utilizadas por la impresora.

Posteriormente se debe proceder con la orientación del modelo y generación de soportes,

aspectos que tienen un impacto directo en la calidad final de la pieza.

### 7.2. Orientación del modelo

La orientación del modelo dentro del volumen de impresión es un factor crítico cuando se

trabaja con materiales elastoméricos, ya que una orientación inadecuada puede generar

defectos como:

- Atrapamiento de resina líquida
- Formación de burbujas internas
- Deformaciones durante el curado
- Colapso de superficies delgadas

Para minimizar estos riesgos, se recomienda orientar el modelo de manera que las cavidades

internas faciliten el drenaje de la resina durante la impresión, evitando que queden zonas

donde el material líquido pueda quedar atrapado. Asimismo, es conveniente evitar que

superficies extensas queden completamente paralelas a la plataforma de impresión, ya que

esto puede generar tensiones adicionales durante el proceso. Finalmente, debe procurarse que

las regiones anatómicas más delicadas del modelo cuenten con un soporte adecuado que

garantice su estabilidad y preserve la fidelidad de la geometría durante la fabricación.

En el caso de modelos cardíacos, suele ser conveniente aplicar una inclinación moderada del

modelo (aproximadamente entre 20° y 40°) respecto a la plataforma de impresión. Esta

inclinación favorece:

- El drenaje de resina desde cavidades internas
- Una distribución más uniforme de las fuerzas de desprendimiento
- Una reducción del riesgo de formación de burbujas o colapsos locales

La orientación final debe evaluarse visualmente en PreForm para asegurar que las estructuras

anatómicas complejas (por ejemplo, vasos o cavidades) no queden orientadas de forma que

puedan retener resina líquida durante el proceso.

### 7.3. Generación de soportes para materiales elastoméricos

Los materiales elastoméricos presentan un comportamiento diferente al de resinas rígidas

durante la impresión. Debido a su flexibilidad, las piezas pueden deformarse más fácilmente

durante las fases de desprendimiento de cada capa.

Por esta razón, se recomienda utilizar una densidad de soportes mayor que la utilizada

normalmente para materiales rígidos.

Configuración recomendada

En PreForm, los soportes pueden generarse utilizando la opción:

Supports → Auto Generate Selected

Posteriormente se recomienda revisar manualmente los soportes generados.

Las recomendaciones generales incluyen:

- Utilizar densidad de soportes media a alta
- Reforzar las zonas inferiores del modelo
- Añadir soportes adicionales en superficies amplias
- Asegurar soporte en geometrías delgadas o salientes

También es importante evitar, en la medida de lo posible, la colocación de soportes en zonas

anatómicas críticas que deban permanecer visualmente limpias para facilitar su observación

o manipulación posterior. Una adecuada distribución de soportes contribuye a reducir

deformaciones durante el proceso de impresión, mantener la estabilidad del modelo a lo largo

de la fabricación y mejorar la precisión geométrica del biomodelo final.

### 7.4. Parámetros de impresión en Form 4 para Silicone 40A

Los parámetros de impresión utilizados para Silicone 40A en la impresora Form 4 se

encuentran preconfigurados dentro del perfil del material en PreForm. No obstante, es

importante comprender los parámetros principales que influyen en el proceso de fabricación.

Los parámetros más relevantes incluyen:

Parámetro | Configuración recomendada
Tecnología de impresión | LFD (Low Force Display)

Altura de capa | Definida automáticamente por el perfil del material
Material | Silicone 40A
Estrategia de exposición | Controlada automáticamente por PreForm
Soportes | Generados automáticamente y ajustados manualmente
Poscurado | Descrito en la sección 9 de esta guía

La tecnología LFD (Low Force Display) utilizada por la Form 4 reduce las fuerzas de

desprendimiento durante la impresión, lo cual resulta especialmente importante cuando se

fabrican piezas flexibles o geometrías complejas.

Una vez configurados estos parámetros y verificada la orientación del modelo, el archivo

puede enviarse a la impresora para iniciar el proceso de fabricación del biomodelo cardíaco

flexible.

Es importante que el modelo haya sido previamente preparado con un espesor mínimo de

pared de 2 mm, tal como se describe en la Sección 6.4. Espesores inferiores pueden generar

deformaciones durante la impresión o comprometer la integridad del biomodelo durante su

manipulación.

La correcta configuración de estas variables permite obtener biomodelos con alta fidelidad

anatómica, estabilidad estructural y comportamiento mecánico adecuado para actividades de

simulación y manipulación.

### 8. Fabricación de la base de soporte anatómico y componentes

estructurales

Los componentes estructurales del sistema han sido diseñados para proporcionar estabilidad

mecánica al biomodelo flexible y contextualizar la práctica de simulación. Estos archivos se encuentran disponibles en el repositorio adjunto en formato STL y están optimizados para su

fabricación mediante Modelado por Deposición Fundida (FDM).

### 8.1. Material recomendado

Para la fabricación de la base de soporte y la cubierta torácica, se establece como estándar el

uso de PLA.

El PLA ofrece una alta rigidez estructural, baja contracción térmica (warping) y facilidad de

impresión en equipos convencionales. Debido a que estas piezas no requieren contacto con

fluidos biológicos ni procesos de esterilización agresivos, el PLA garantiza la estabilidad del

sistema a un costo mínimo.

### 8.2. Configuración de impresión (Slicing)

Para asegurar que los mecanismos de sujeción (específicamente el sistema de "garra" y los

puntos de pivote) mantengan su integridad bajo la manipulación del usuario, se recomiendan

los siguientes parámetros de impresión:

Parámetro | Configuración recomendada
Altura de capa | 0.2 mm (Equilibrio entre resolución y tiempo)
Grosor de pared (Perímetros) | Mínimo 3 capas (Vital para la resistencia de los encastres)
Relleno (Infill) | 15% - 20%
Patrón de relleno | Giroide o Rejilla (Proporciona resistencia multidireccional)
Capas superiores/inferiores | 4 capas

Temperatura de boquilla | Según | especificación | del | fabricante

(Típicamente 200°C - 215°C)

### 8.3. Consideraciones del diseño de sujeción

La base de soporte anatómico cuenta con un mecanismo de sujeción tipo garra diseñado

específicamente para interactuar con elastómeros de baja dureza (como el Silicone 40A).

Ajuste mecánico: Tras la impresión, se debe verificar que las pinzas del mecanismo se

muevan libremente. En caso de fricción excesiva debido a tolerancias de la impresora, se

recomienda un lijado ligero en las zonas de contacto del eje.

Interfaz con el biomodelo: El diseño permite que el corazón sea "abrazado" por la garra,

distribuyendo la presión de contacto para evitar desgarros en el material flexible durante la

práctica de sutura o manipulación.

### 8.4. Ensamble con la cubierta torácica pediátrica

Una vez fabricados los componentes estructurales mediante impresión FDM, se procede al

ensamble del sistema de simulación, integrando la base de soporte anatómico, el biomodelo

cardíaco flexible y la cubierta torácica pediátrica.

El diseño del sistema permite un ensamble modular, de modo que el usuario pueda utilizar el

corazón únicamente con la base de soporte o integrar adicionalmente la cubierta torácica

cuando se requiera proporcionar un mayor contexto anatómico.

El procedimiento de ensamblaje recomendado es el siguiente:

### 1. Instalación del biomodelo en la base de soporte

El biomodelo cardíaco flexible debe colocarse entre las garras del mecanismo de sujeción.

Las pinzas del sistema tipo garra están diseñadas para ejercer una presión moderada que

permita estabilizar el modelo sin generar deformaciones permanentes en el elastómero.

### 2. Verificación de estabilidad

Una vez posicionado el biomodelo, se debe verificar que el modelo permanezca estable

durante la manipulación. El sistema debe permitir movimientos manuales moderados sin que

el corazón se desplace o gire dentro del mecanismo de sujeción.

### 3. Montaje de la cubierta torácica pediátrica

La cubierta torácica puede instalarse alineando los puntos de encastre diseñados en la base

estructural. Estos puntos de unión permiten posicionar la cubierta de manera repetible,

manteniendo la orientación anatómica correcta del sistema.

### 4. Ajuste final del sistema

Tras el ensamblaje, se recomienda verificar que:

- La cubierta no interfiera con el acceso al biomodelo durante la práctica
- El biomodelo permanezca visible desde los ángulos de observación principales
- Los componentes estructurales no generen compresión excesiva sobre el material

elastomérico

Este sistema de integración permite recrear un entorno anatómico simplificado del tórax

pediátrico, facilitando la comprensión espacial de las estructuras cardíacas y mejorando la

experiencia de simulación durante actividades educativas o demostrativas.

El diseño modular del sistema también permite desmontar fácilmente los componentes para

mantenimiento, reemplazo del biomodelo o transporte del sistema, manteniendo la

funcionalidad general del conjunto.

### 9. Posprocesamiento del biomodelo

El posprocesamiento constituye una etapa crítica en la fabricación de biomodelos impresos

con Silicone 40A, ya que determina en gran medida las propiedades mecánicas finales del

material, la calidad superficial del modelo y la eliminación de residuos de material no curado.

Debido a la naturaleza elastomérica del material, el procedimiento de limpieza difiere de

otros fotopolímeros utilizados en manufactura aditiva. En esta sección se describen las recomendaciones basadas en las guías técnicas del fabricante Formlabs, adaptadas al flujo de

trabajo de esta guía.

### 9.1. Lavado del biomodelo impreso

Según las recomendaciones del fabricante, el procedimiento estándar de limpieza para

Silicone 40A consiste en un lavado utilizando una mezcla de solventes dentro de un sistema

Form Wash.

El procedimiento estándar recomendado por Formlabs utiliza:

20 % n-butyl acetate + 80 % alcohol isopropílico (IPA) durante 20 minutos.

No obstante, debido al olor característico del n-butyl acetate, el fabricante también describe

un procedimiento alternativo utilizando únicamente IPA y limpieza ultrasónica, el cual fue

considerado en este flujo de trabajo.

Procedimiento alternativo con IPA y baño ultrasónico

1. Retirar el modelo de la plataforma de impresión.
2. Colocar las piezas en un recipiente con IPA suficiente para cubrir completamente el

modelo.

3. Introducir el recipiente dentro de un baño ultrasónico lleno de agua.

Formlabs recomienda utilizar limpiadores ultrasónicos en el rango de:

35–45 kHz

4. Someter las piezas a sonicación durante 2 a 3 minutos.

Durante el lavado es normal observar que el IPA se vuelva turbio o que aparezcan residuos

de silicona en suspensión, ya que la silicona no es soluble en IPA.

5. Repetir el proceso utilizando IPA limpio en un segundo recipiente para asegurar la

eliminación completa de residuos.

Una pieza correctamente lavada no debe presentar restos visibles de silicona en su superficie.

6. Después del lavado, dejar secar las piezas al aire durante al menos 30 minutos antes

de iniciar el proceso de curado.

### 9.2. Remoción de soportes

La remoción de soportes en materiales elastoméricos requiere mayor cuidado que en resinas

rígidas, ya que el material puede deformarse o desgarrarse si se aplican fuerzas excesivas.

Se recomienda retirar los soportes después del lavado, cuando el material aún conserva cierta

flexibilidad.

Herramientas recomendadas:

- Pinzas de precisión
- Cortadores de modelado
- Bisturí o cuchilla fina

Recomendaciones de manipulación:

- Retirar primero los soportes principales
- Evitar tracciones bruscas
- Cortar los soportes cerca de su punto de contacto

La flexibilidad del Silicone 40A permite flexionar ligeramente la pieza para acceder a

soportes ubicados en zonas internas.

### 9.3. Curado final del biomodelo

Después del lavado y la remoción de soportes, el modelo debe someterse a un proceso de

curado térmico y UV para alcanzar sus propiedades mecánicas finales.

El fabricante recomienda utilizar el sistema Form Cure.

Configuración recomendada por Formlabs

Parámetro | Configuración
Material | Silicone 40A
Temperatura | 60 °C

Tiempo | 45 minutos

Procedimiento:

1. Colocar las piezas dentro de un recipiente de vidrio o contenedor transparente a UV.
2. Sumergir completamente las piezas en agua.
3. Introducir el recipiente dentro del equipo Form Cure.
4. Ejecutar el ciclo de 45 minutos a 60 °C.

La inmersión en agua durante el curado ayuda a:

- Mejorar la transferencia térmica
- Favorecer la polimerización homogénea
- Reducir defectos superficiales

El fabricante indica que un curado adicional no afecta negativamente el material,

especialmente en piezas gruesas o voluminosas.

10.Integración y ensamblaje del sistema de simulación

Una vez completadas las etapas de fabricación y posprocesamiento de los distintos

componentes, se procede a la integración del sistema de simulación. Esta etapa consiste en

ensamblar el biomodelo cardíaco flexible fabricado en Silicone 40A con la base de soporte

anatómico impresa en PLA y, cuando se requiera, incorporar la cubierta torácica estructural.

El objetivo de esta fase es garantizar que el biomodelo se mantenga estable durante la

manipulación, preserve su orientación anatómica correcta y permita recrear un entorno de

trabajo que facilite actividades de demostración, entrenamiento o simulación básica.

El sistema ha sido diseñado con un enfoque modular, permitiendo que cada componente

pueda desmontarse fácilmente para mantenimiento, transporte o sustitución del biomodelo.

### 10.1. Montaje del biomodelo en la base de soporte

El primer paso del ensamblaje consiste en fijar el biomodelo cardíaco flexible dentro del

mecanismo de sujeción tipo garra presente en la base de soporte anatómico.

Este mecanismo ha sido diseñado para interactuar con materiales elastoméricos de baja

dureza, como el Silicone 40A, permitiendo sujetar el modelo sin comprometer su integridad

estructural.

Procedimiento de montaje:

1. Colocar el biomodelo cardíaco entre las pinzas del sistema de sujeción tipo garra.
2. Ajustar gradualmente la apertura de las pinzas hasta que el modelo quede firmemente

sostenido.

3. Verificar que la presión ejercida sea suficiente para evitar el desplazamiento del

modelo, pero sin comprimir excesivamente el material elastomérico.

Debido a la naturaleza flexible del Silicone 40A, una compresión excesiva puede provocar

deformaciones en la geometría anatómica y alteraciones en la forma de las cavidades

internas. Por esta razón, el sistema de sujeción debe ejercer únicamente la presión necesaria

para estabilizar el biomodelo.

### 10.2. Orientación anatómica del biomodelo

Una correcta orientación anatómica del modelo es esencial para que las actividades de

simulación reproduzcan de forma coherente la perspectiva habitual del cirujano o estudiante

durante la manipulación del corazón.

Al instalar el biomodelo en la base se recomienda verificar los siguientes puntos de referencia

anatómica:

- El ápice cardíaco debe orientarse hacia la región inferior del sistema.
- Los grandes vasos (aorta y arteria pulmonar) deben orientarse hacia la región superior

del modelo.

- La superficie anterior del corazón debe quedar orientada hacia el área de acceso del

usuario.

Esta orientación permite que el modelo reproduzca una posición anatómica aproximada a la

del corazón dentro de la cavidad torácica, facilitando la interpretación espacial de las

estructuras cardíacas durante demostraciones o prácticas educativas.

En caso de utilizar modelos con cardiopatías congénitas complejas, puede ser conveniente

ajustar ligeramente la orientación para mejorar la visibilidad de las regiones de interés.

### 10.3. Instalación de la cubierta torácica

Una vez instalado el biomodelo en la base de soporte, puede incorporarse la cubierta torácica

estructural, la cual representa de forma simplificada la cavidad torácica pediátrica y

proporciona mayor contexto anatómico durante la simulación.

Para su instalación, se deben alinear los puntos de encastre de la cubierta con la base

estructural y presionar suavemente hasta asegurar su fijación. Una vez instalada, la cubierta

debe quedar firmemente posicionada sin interferir con el acceso al biomodelo.

Este componente limita parcialmente el campo visual del usuario, contribuyendo a generar

condiciones de manipulación más cercanas a un entorno quirúrgico real.

### 10.4. Verificación y ajustes finales del sistema

Tras completar el ensamblaje del sistema se recomienda realizar una breve verificación para

asegurar el correcto funcionamiento del conjunto.

Los siguientes aspectos deben comprobarse:

- El biomodelo permanece firmemente sujeto dentro del mecanismo de garra
- No existe compresión excesiva del material elastomérico
- El modelo mantiene la orientación anatómica adecuada
- La cubierta torácica se encuentra correctamente acoplada
- No existen componentes sueltos o inestables

- El usuario puede acceder al biomodelo sin interferencias estructurales

También se recomienda realizar una prueba de manipulación ligera, simulando movimientos

típicos durante actividades educativas o de demostración, con el fin de confirmar que el

sistema mantiene su estabilidad.

Una vez verificados estos aspectos, el sistema queda listo para su utilización en actividades

de simulación, enseñanza anatómica o demostraciones clínicas dentro de contextos

educativos o de investigación.

11.Notas finales y recomendaciones

La presente guía describe un flujo de trabajo reproducible para la fabricación e integración

de biomodelos cardíacos anatómicos mediante manufactura aditiva. La correcta

manipulación y almacenamiento de los componentes del sistema contribuye a preservar la

calidad del biomodelo y facilitar su utilización en actividades educativas o demostrativas.

### 11.1. Almacenamiento de biomodelos

Debido a la naturaleza elastomérica del Silicone 40A, el material puede presentar ligera

adhesividad superficial, lo que facilita la acumulación de polvo o partículas durante el

almacenamiento. Para preservar el biomodelo antes de su uso se recomienda:

- Guardar los biomodelos en recipientes cerrados o contenedores protectores.
- Mantenerlos alejados de polvo o pelusa.
- Evitar la exposición prolongada a la luz solar directa, ya que la radiación UV puede

acelerar la degradación del material.

Cuando se planifiquen actividades educativas que requieran prácticas de manipulación, corte

o sutura, se recomienda disponer de varios biomodelos previamente fabricados, ya que este

tipo de intervenciones modifica permanentemente la geometría del modelo.

### 11.2. Uso del biomodelo

Los biomodelos pueden utilizarse en diferentes contextos educativos dependiendo del tipo

de actividad. En demostraciones anatómicas o exposiciones educativas, el modelo puede

manipularse sin alterar su integridad estructural. Sin embargo, cuando el biomodelo se utiliza

para prácticas de corte o sutura, el modelo debe considerarse de uso único, ya que estas

intervenciones modifican de forma permanente el material elastomérico.

### 11.3. Consideración final

La disponibilidad de guías técnicas claras para la fabricación de biomodelos anatómicos

contribuye a facilitar la incorporación de herramientas de simulación física en entornos

educativos. Mediante el flujo de trabajo descrito en este documento, es posible transformar

modelos digitales en representaciones físicas que apoyan la comprensión tridimensional de

la anatomía cardíaca y enriquecen las actividades de enseñanza y demostración en el ámbito

de la educación médica.
